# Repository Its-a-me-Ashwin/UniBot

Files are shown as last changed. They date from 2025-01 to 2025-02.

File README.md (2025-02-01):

# UniBot: A Cost-Effective Universal Wheeled Robot Platform

**UniBot** is a versatile, cost-effective robotic platform designed for human-robot interaction (HRI) and navigation-based research projects. With a maximum continuous payload of 45 kg, UniBot can support up to 60 kg when acceleration is reduced, making it ideal for various experimental and research applications.

<!-- ![](https://github.com/Its-a-me-Ashwin/UniBot/blob/main/images/img2.jpeg) | ![]([https://...Ocean.png](https://github.com/Its-a-me-Ashwin/UniBot/blob/main/images/img1.jpeg)) -->

## Features
- **Max Continuous Payload**: 45 kg
- **Max Payload (Reduced Acceleration)**: 60 kg
- **Universal Wheeled Design**: Suitable for indoor navigation and HRI applications
- **Cost-Effective**: Built for under 500 USD
  
## Hardware
All CAD and STL files for the robot platform are available on [Onshape](https://cad.onshape.com/documents/59060569869ff0b1603c8808/w/daa640d62e3ffdb959e3981d/e/3620547f53db6f14c46e0bf9).

### Bill of Materials

# Parts List

| Item | Description | Quantity |
|---|---|---|
| **Motors** | [Scooter Motors](https://www.amazon.com/dp/B0BBVVV962?ref=ppx_yo2ov_dt_b_fed_asin_title) | 2 |
| **Motor Driver** | [ODrive 3.6](https://odriverobotics.com/shop/odrive-v36) | 1 |
| **Toroidal Inductors** | - | 2 |
| **Capacitors** | 22nF [Capacitors](https://www.amazon.com/dp/B094HRK8QX?ref=ppx_yo2ov_dt_b_fed_asin_title) | 6 |
| **Prototype Board** | [Adafruit Prototype Board](https://www.adafruit.com/product/1609) | 1 |
| **M3 Bolts, Nuts, and Spacers** | - | As needed |
| **M8x20 Bolts and Nuts** | - | 24 |
| **M10x10 Bolts and Nuts** | - | 4 |
| **M12x10 Bolts** | - | 4 |
| **Caster Wheels (4cm diameter)** | - | 2 |
| **DC-DC Converter with USB-C PD Output** | eBay | 1 |
| **Battery (36V or 24V, min 2.5Ah)** | eBay | 1 |

## Total Estimated Cost: ~$500 USD

## Software
### Ongoing Development (For Experimental Use)
The initial Python code to configure both scooter motors is available, including a command-line interface (CLI) for controlling both motors. As the software is still in progress, it may be subject to changes. Use with caution in experimental setups.

---

For questions, contributions, or further information, please feel free to reach out or please checkout [this](https://github.com/Its-a-me-Ashwin/SpeedyNav) repo for a n indepth look at its appliacation (in progress).

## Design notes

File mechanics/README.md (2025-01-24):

# Fabrication Instructions

This folder contains all the parts required to build the robot. You will need to **3D-print** several components and **laser-cut** others, based on the details below.

---

## 3D-Printed Parts

- **Material**: Use a tough plastic such as **ABS**.  
- **Infill**: Print with **80% infill** for optimal strength.  
- **Alternative Filaments**: Stronger filaments (e.g., PETG, Nylon, or Carbon Fiber-reinforced) are optional. ABS is sufficient if cost is a concern or you already have it on hand.

---

## Laser-Cut Parts

- **Material Thickness**: All laser-cut parts should be **5 mm** thick.  
- **Material Options**: Acrylic, plywood, MDF, or aluminum.  
- **Recommendations**:  
  - **MDF** and **acrylic** often provide a good balance of cost, availability, and performance.  
  - If weight or rigidity is critical, consider aluminum.  
  - Plywood can also be used for a more natural aesthetic.

---

## Additional Notes

1. **Check CAD Files**: Ensure you have the correct dimensions and tolerances from the design files before fabrication.  
2. **Assembly**: After printing and cutting, verify all parts fit correctly before final assembly.  
3. **Safety**: Follow best practices when using 3D printers, laser cutters, and other fabrication tools.

---

_You can refer back to the main documentation or CAD designs for further details on part orientation, supports, or finishing steps._

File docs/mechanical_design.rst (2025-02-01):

Mechanical Design
=================

CAD Files
---------

Link to the step files. 
**Example**:
`Download CAD Files <../_assets/assembly.zip>`_
It is available at ../_assets/assembly.zip

Exploded Views
--------------

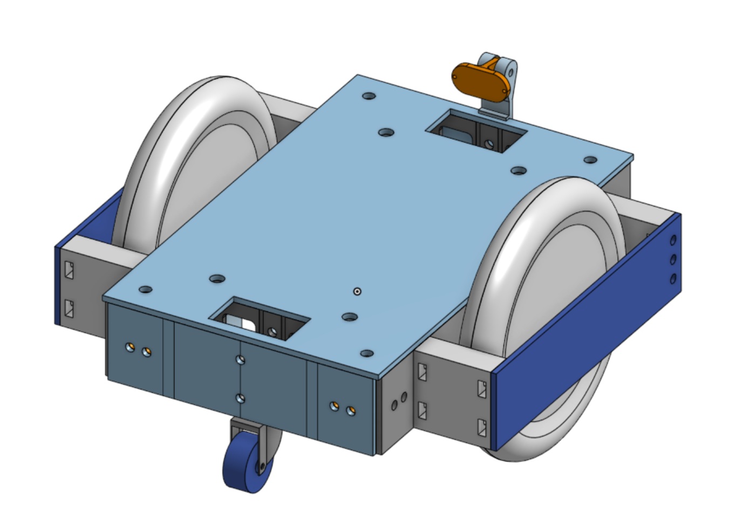
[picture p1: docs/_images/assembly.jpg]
Exploded View


Discuss any important design features or constraints.

Materials & Dimensions
----------------------

.. list-table::
   :widths: 30 50 20
   :header-rows: 1

   * - **Item**
     - **Description**
     - **Quantity**
   * - **Motors**
     - `Scooter Motors <https://www.amazon.com/dp/B0BBVVV962?ref=ppx_yo2ov_dt_b_fed_asin_title>`_
     - 2
   * - **Motor Driver**
     - `ODrive 3.6 <https://odriverobotics.com/shop/odrive-v36>`_
     - 1
   * - **Toroidal Inductors**
     - -
     - 2
   * - **Capacitors**
     - 22nF `Capacitors <https://www.amazon.com/dp/B094HRK8QX?ref=ppx_yo2ov_dt_b_fed_asin_title>`_
     - 6
   * - **Prototype Board**
     - `Adafruit Prototype Board <https://www.adafruit.com/product/1609>`_
     - 1
   * - **M3 Bolts, Nuts, and Spacers**
     - -
     - As needed
   * - **M8x20 Bolts and Nuts**
     - -
     - 24
   * - **M10x10 Bolts and Nuts**
     - -
     - 4
   * - **M12x10 Bolts**
     - -
     - 4
   * - **Caster Wheels (4cm diameter)**
     - -
     - 2
   * - **DC-DC Converter with USB-C PD Output**
     - eBay
     - 1
   * - **Battery (36V or 24V, min 2.5Ah)**
     - eBay
     - 1
   * - **ABS Filament**
     - 500g spool for 3D printing
     - 1
   * - **Material Sheet (Acrylic, Aluminum, or MDF)**
     - 800x600mm piece for structural components
     - 1

**Total Estimated Cost**: ~500 USD

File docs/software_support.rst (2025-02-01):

Software Support
================

Getting Started
---------------

#. **Set up a Raspberry Pi**:
   - If you use a Raspberry Pi or a similar single-board computer, please set it up with an OS.

   - It is recommended to update to the latest version of the OS, set up a WiFi connection, and enable SSH.
   
   - Also, set up Bluetooth and connect a controller to the Raspberry Pi for debugging later. Refer to :doc:`bluetooth_setup` for instructions.

#. **Install Dependencies**:
   - Install Python and the required packages.

   .. code-block:: bash

      sudo apt update
      sudo apt-get install python3 python3-pip

      pip3 install odrive

      cd ~
      git clone https://github.com/<removed-for-anonymity>/Unibot.git
      cd Unibot/code
      pip install -e .

Initial Calibration
-------------------

Run the following command while the robot is on a stand with its wheels free to move. Ensure that the ODrive has power before proceeding.

#. **Configure the ODrive**:

   .. code-block:: bash

      sudo ./Unibot/code/src/config.sh

   This command takes about one minute to run, and the robot's wheels will move during the process. Once it completes, **do not** change the orientation of the wires.

   At this point, your robot is ready to use.

Example Usage of the Repository
-------------------------------

Run the folloing to set up a simple waypoint mission to make the robot move around.

.. code-block:: bash

   #!/usr/bin/env python3
   import time
   from unibot import Unibot
   from unibot import Waypoints, Waypoint  # Or "from unibot.waypoints import Waypoints, Waypoint" if you prefer

   def main():
      # 1. Create your Unibot instance
      unibot = Unibot(max_speed=50, max_acceleration=10)

      # 2. Set the motors to closed-loop control
      unibot.motor_controller.setClosedLoopControl(0)
      unibot.motor_controller.setClosedLoopControl(1)
      print("Motors set to CLOSED-LOOP control.")

      # 3. Define some waypoints
      #    Each Waypoint has a direction (x, y), a speed, a duration, and an optional delay after the move
      waypoints = Waypoints()
      waypoints.add_waypoint(Waypoint(direction=(0, 1), speed=0.5, duration=3.0, delay=1.0))  # Move forward
      waypoints.add_waypoint(Waypoint(direction=(1, 0), speed=0.3, duration=2.0, delay=1.0))  # Turn right
      waypoints.add_waypoint(Waypoint(direction=(0, -1), speed=0.5, duration=3.0, delay=0.5)) # Move backward
      waypoints.add_waypoint(Waypoint(direction=(-1, 0), speed=0.3, duration=2.0, delay=0.0)) # Turn left

      # 4. Execute the waypoints asynchronously
      print("Executing waypoints...")
      waypoints.execute_async(unibot)

      # (Optional) Let the robot do its moves for 10 seconds
      time.sleep(10)

      # 5. Stop execution (if you want to halt prematurely or after finishing)
      print("Stopping waypoints execution...")
      waypoints.stop_execution(unibot)

      # Deactivate the motors or keep them in closed-loop as you see fit
      unibot.motor_controller.setIdle(0)
      unibot.motor_controller.setIdle(1)
      print("Motors set to IDLE. Done.")

   if __name__ == "__main__":
      main()

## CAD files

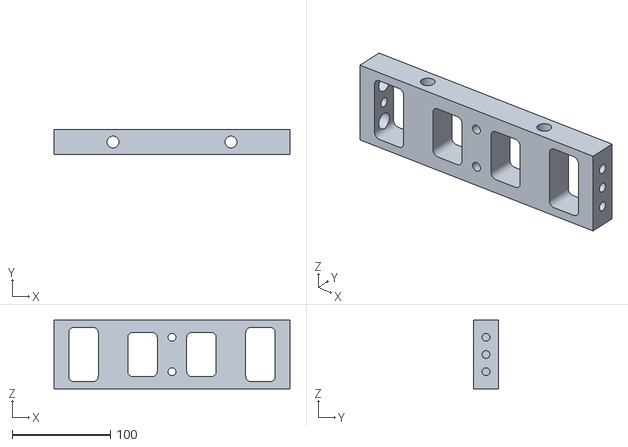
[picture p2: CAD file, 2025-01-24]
mechanics/3d-prints/MainBracket x 2.stl
240.0 x 25.0 x 70.0

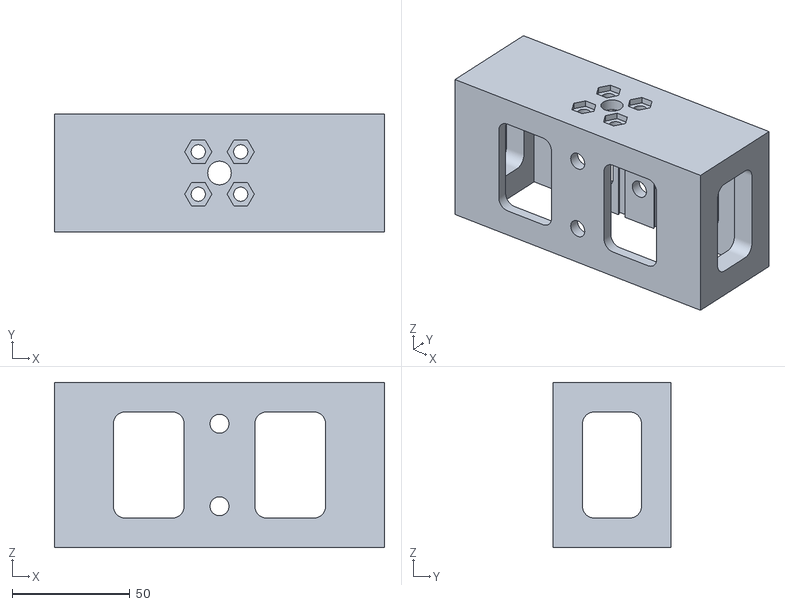
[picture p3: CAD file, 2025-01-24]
mechanics/3d-prints/ChasterWheelHolder x 2.stl
140.0 x 50.0 x 70.0

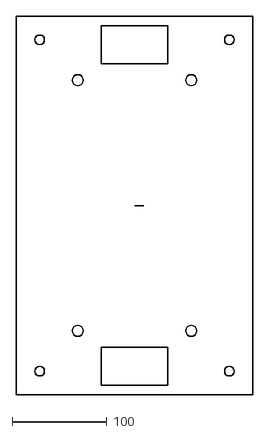
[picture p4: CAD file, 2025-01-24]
mechanics/laser-cuts/TopPlate x 2.dxf
250.0 x 400.0

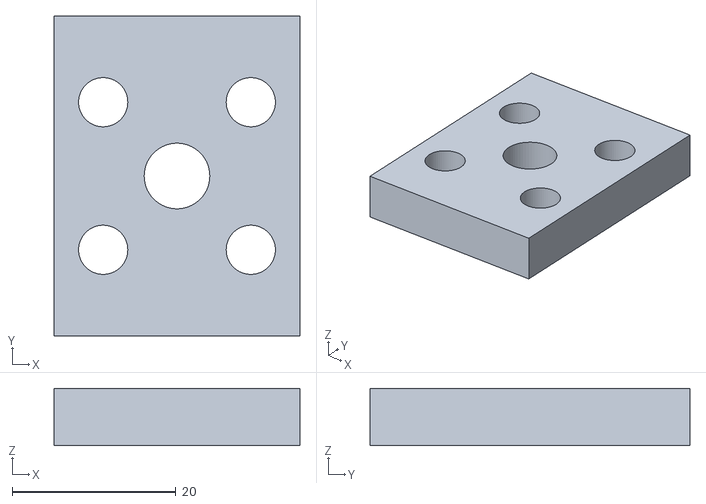
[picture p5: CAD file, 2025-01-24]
mechanics/3d-prints/ChassisWheelAttachment x 2.stl
30.0 x 39.0 x 7.00

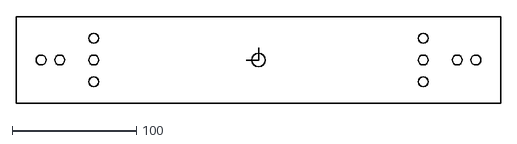
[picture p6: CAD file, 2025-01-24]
mechanics/laser-cuts/SidePlate x 2.dxf
390.0 x 70.0

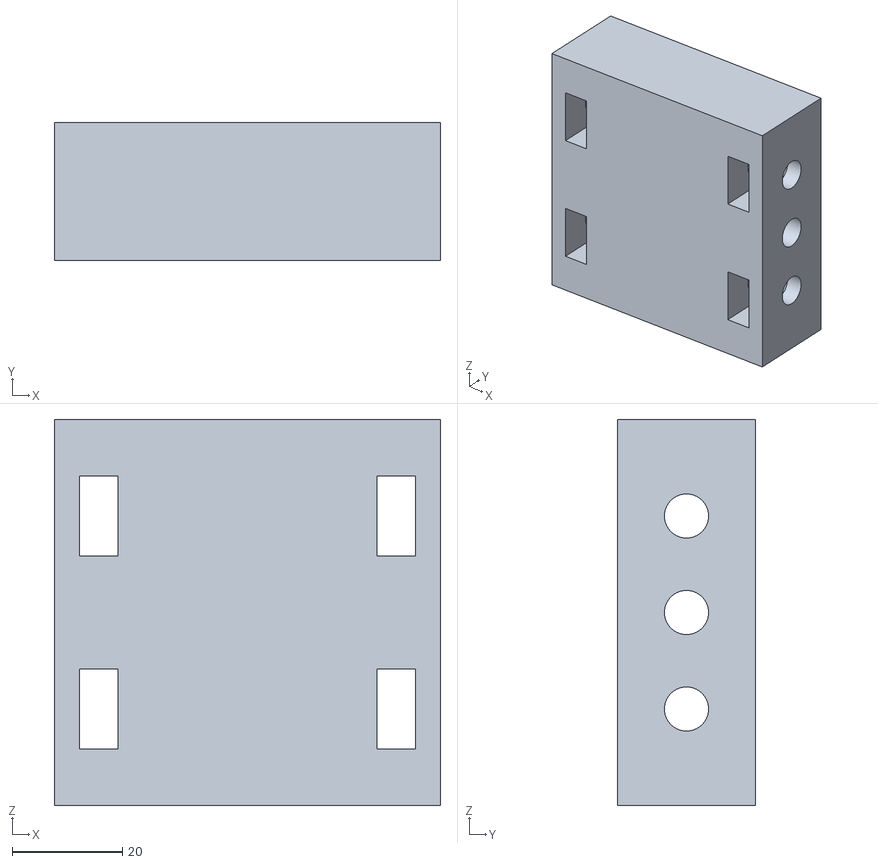
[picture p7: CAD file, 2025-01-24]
mechanics/3d-prints/WheelSpacer x 4.stl
70.0 x 25.0 x 70.0

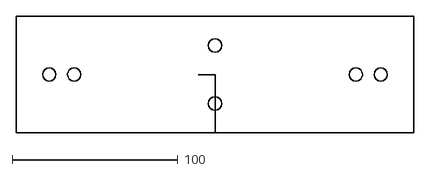
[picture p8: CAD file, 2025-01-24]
mechanics/laser-cuts/FrontPlate x 2.dxf
240.0 x 70.0

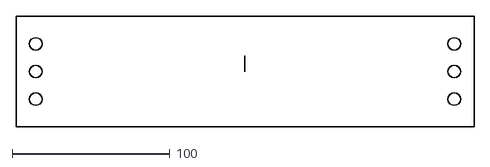
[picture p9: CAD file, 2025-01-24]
mechanics/laser-cuts/WheelHolder x 2.dxf
290.0 x 70.0

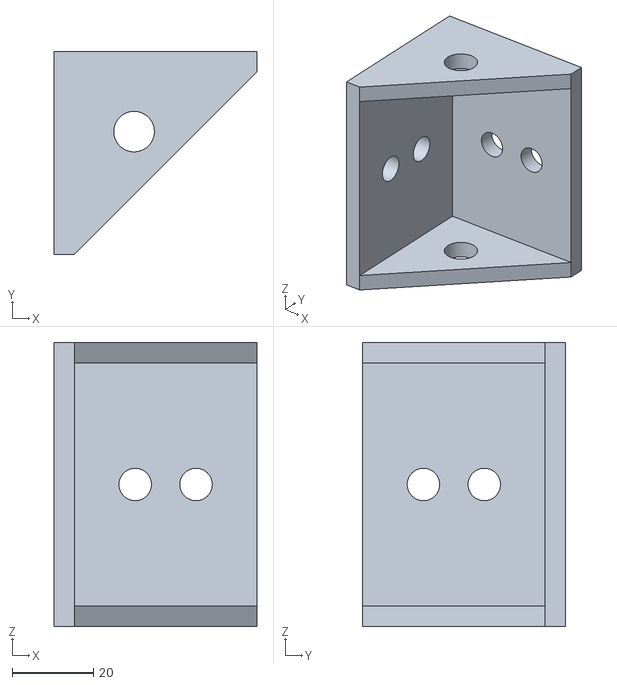
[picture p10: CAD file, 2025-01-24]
mechanics/3d-prints/LBracket x 4.stl
50.0 x 50.0 x 70.0

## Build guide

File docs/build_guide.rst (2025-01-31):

Build Guide
===========

Introduction
------------

This page walks you through assembling the robot step by step. It also provides an overview of the necessary tools, materials, and prerequisites.

Mechanical Assembly
-------------------

#. **Print or Laser-Cut Parts**: Instructions on how to obtain the mechanical parts.
#. **Gather Fasteners**: List of required screws, nuts, washers, etc.

#. **Parts List**:
   - 3D print all the necessary parts. It is recommended to use ASA or ABS with 80% infill and at least 8 walls to increase strength.
   - Laser-cut all the provided DXF files using either acrylic or MDF. Non-structural plates, such as the bottom plate, can be cut from plywood.

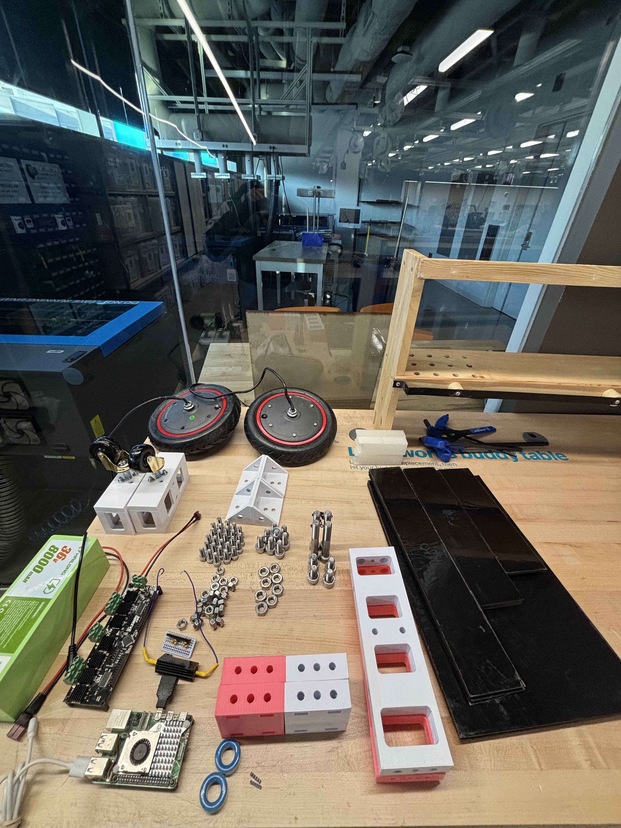
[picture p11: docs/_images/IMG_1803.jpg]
Assembly Step 1


#. **Building Steps**:

   #. **Step 1**:
      Gather the main brackets and bolts.

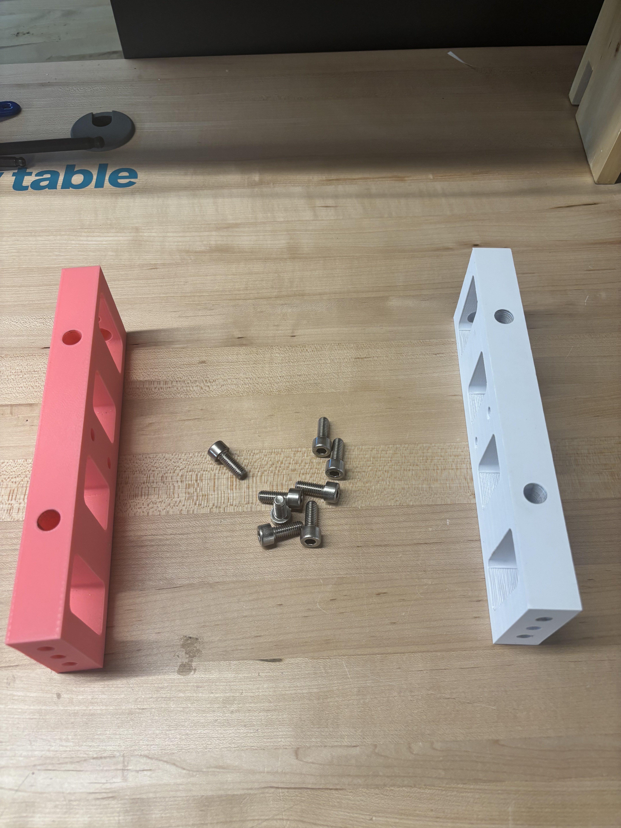
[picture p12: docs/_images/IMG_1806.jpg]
   

   #. **Step 2**:
      Assemble the main brackets and bolts.

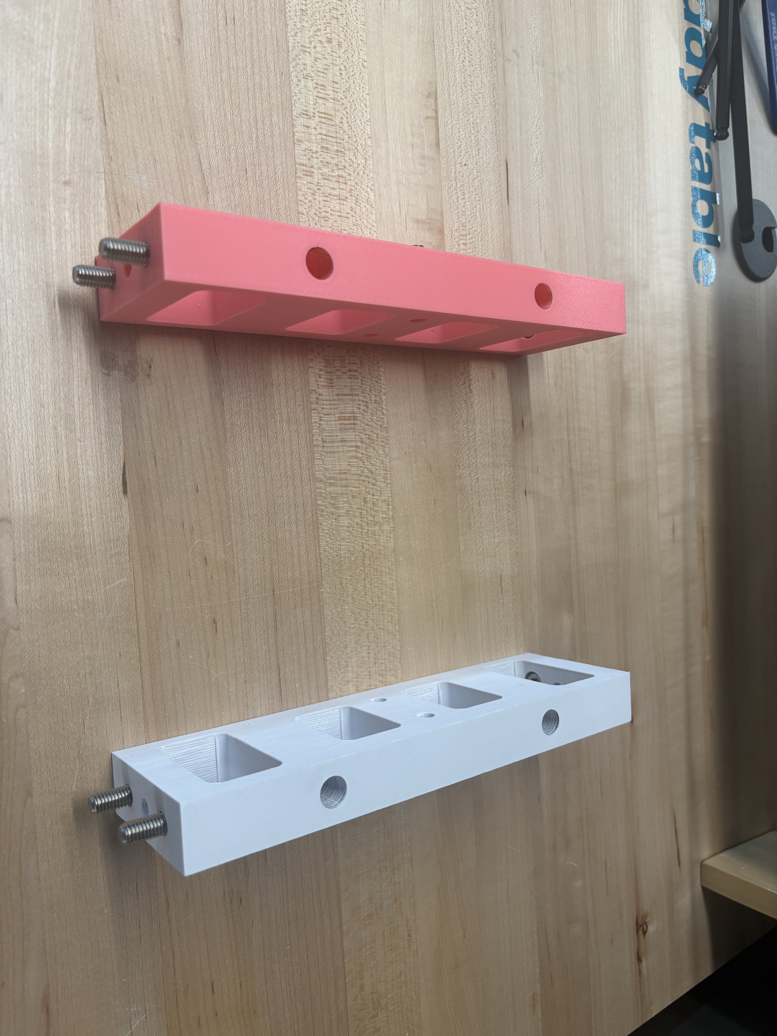
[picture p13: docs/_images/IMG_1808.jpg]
   

   #. **Step 3**:
      Attach the two longer boards to the main brackets using eight M8x20 bolts. The bolts will be loose for now, which is fine.

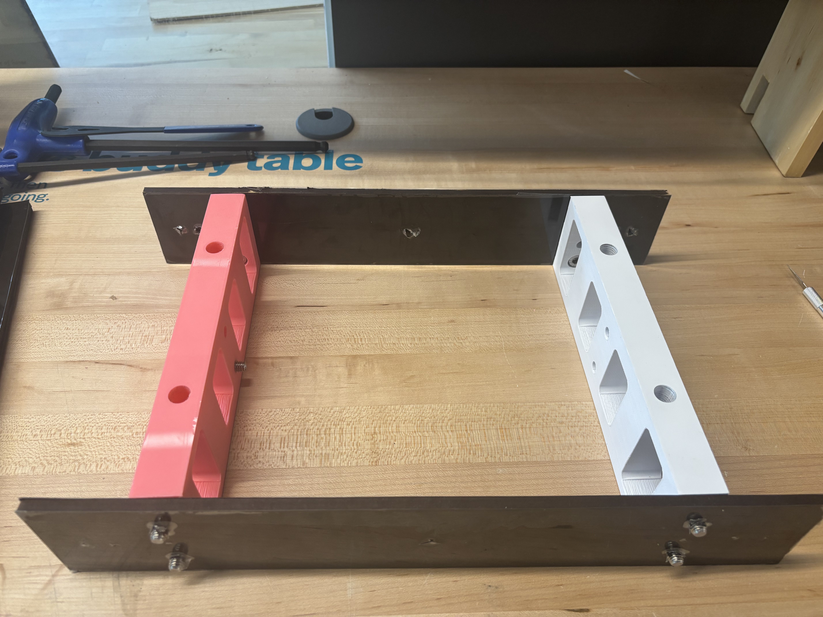
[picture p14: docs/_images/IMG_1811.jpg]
   

   #. **Step 4**:
      Insert the M8 nuts into the holes in the spacers. Tighten all eight M8x20 bolts using an Allen key with a rounded head.

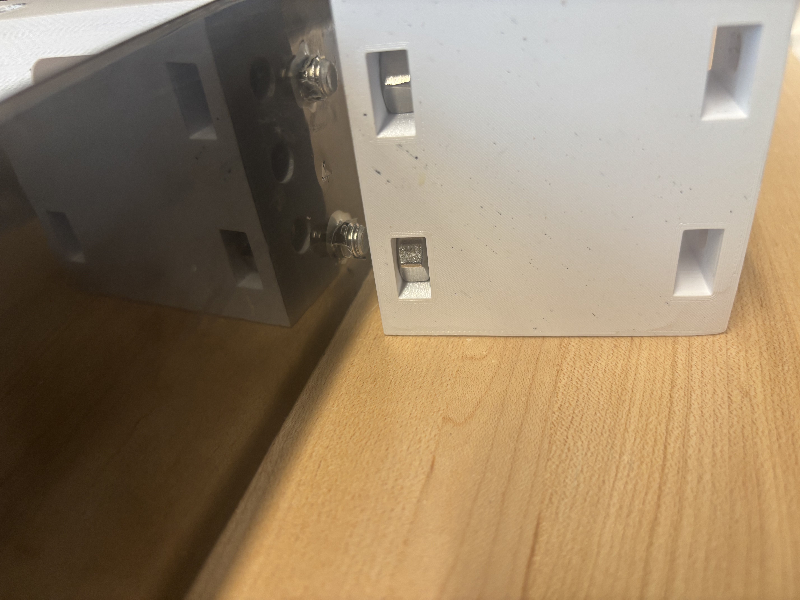
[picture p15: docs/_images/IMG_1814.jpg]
   

   #. **Step 5**:
      Get the angled brackets and attach them to the main frame using M8x20 bolts.

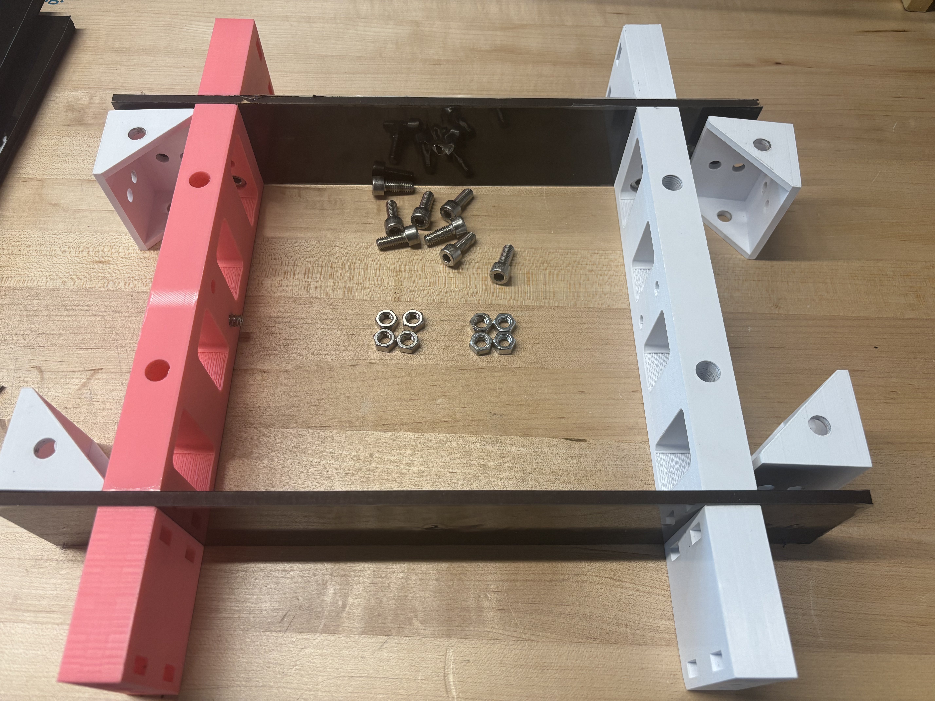
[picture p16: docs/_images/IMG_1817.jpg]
   

   #. **Step 6**:
      Get the two front panels and four M8x20 bolts and nuts. Attach the front and back panels as shown.

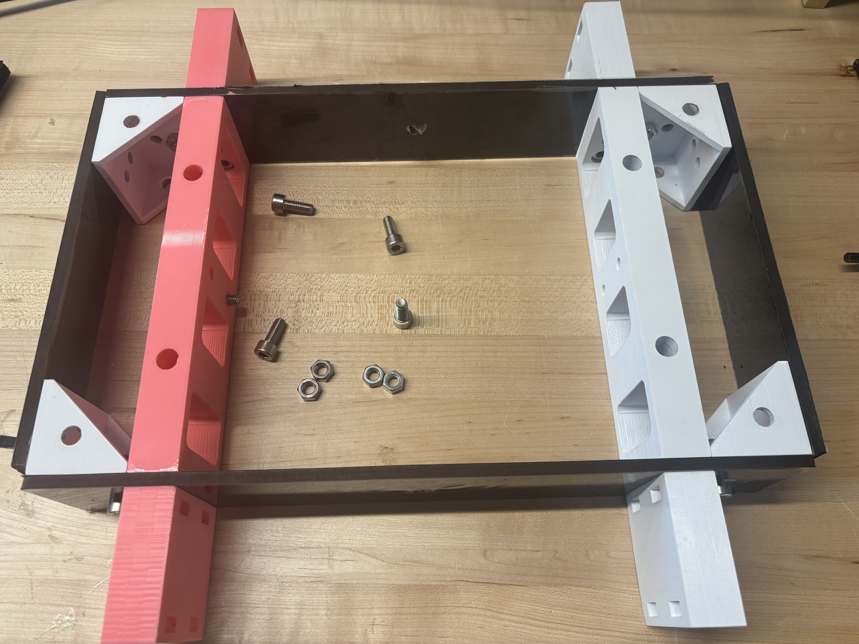
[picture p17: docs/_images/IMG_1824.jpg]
   

   #. **Step 7**:
      Get the M10x20 bolts and attach them through the bottom holes on the angled brackets. Refer to the pictures for details. Use a long Allen key to tighten the bolts.

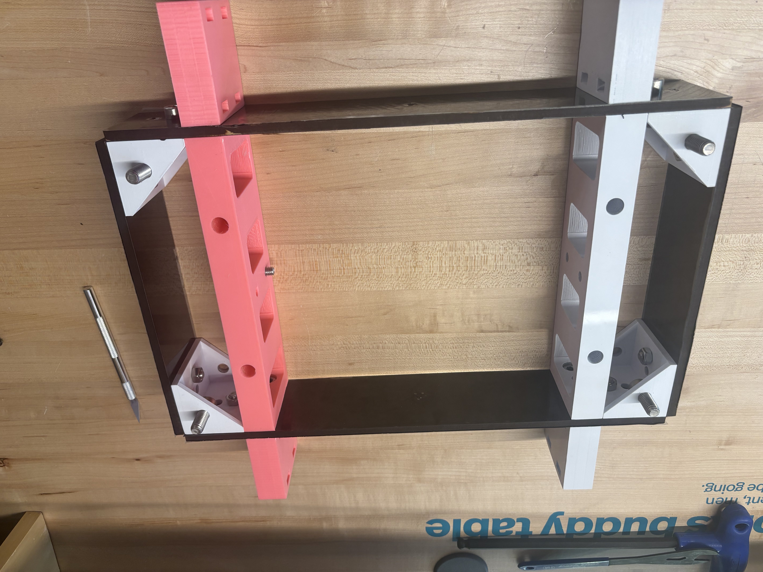
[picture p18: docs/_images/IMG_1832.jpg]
   

   #. **Step 8**:
      Attach the bottom plate (the one with holes for the electronics) to the angled brackets using M10 bolts and nuts. Use M12x10 bolts to reinforce the attachment to the main bracket.

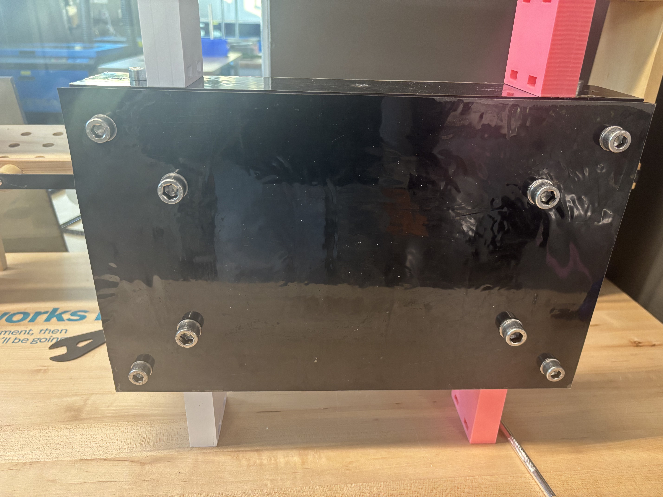
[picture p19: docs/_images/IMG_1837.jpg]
   

   #. **Step 9**:
      Place the robot on its side as shown in the picture. This is how it should look.

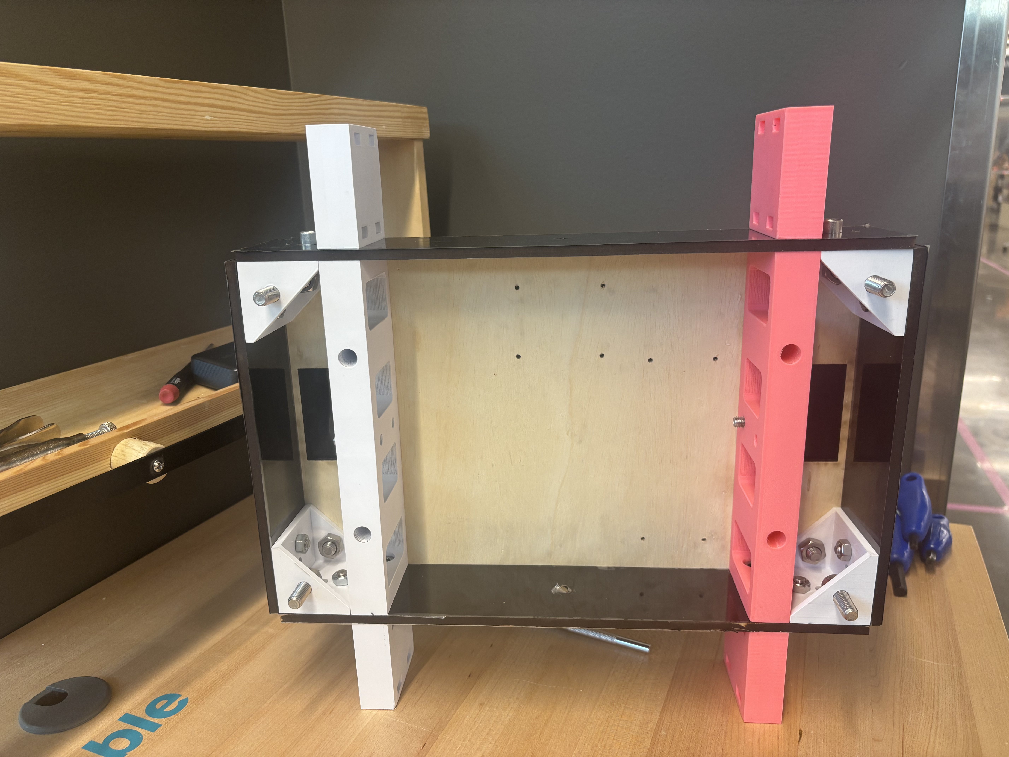
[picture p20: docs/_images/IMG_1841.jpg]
   

   #. **Step 10**:
      Attach the main board (Raspberry Pi 5) using M3 standoffs, nuts, and nylon bolts.

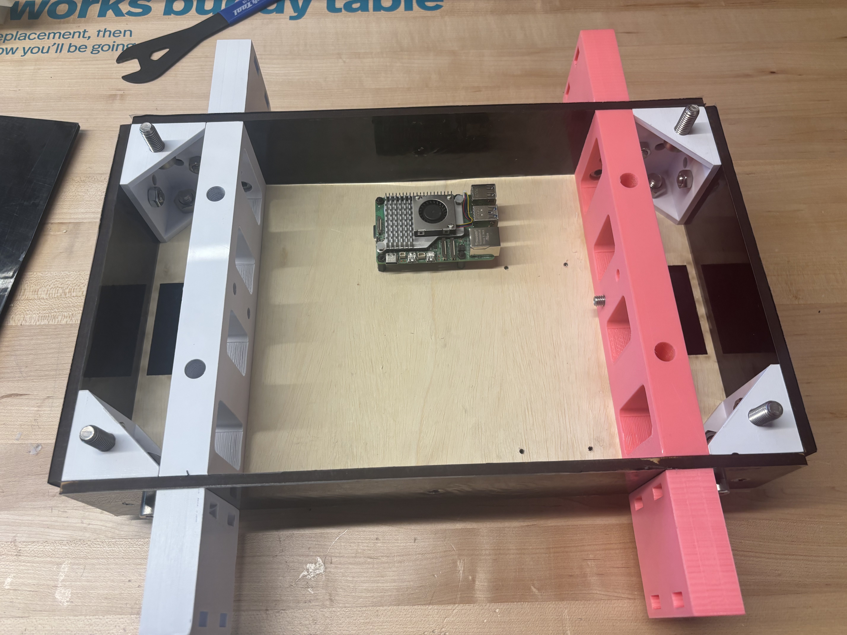
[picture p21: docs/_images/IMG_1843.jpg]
   

   #. **Step 11**:
      Install the scooter motor. Carefully insert the wires into the hole on the side bracket and tighten the main bolt into the panel.
      Ensure that no orthogonal force is applied to the axis, as this may stress the panels. Instead, rotate the bolt while keeping the motor upright to tighten it.

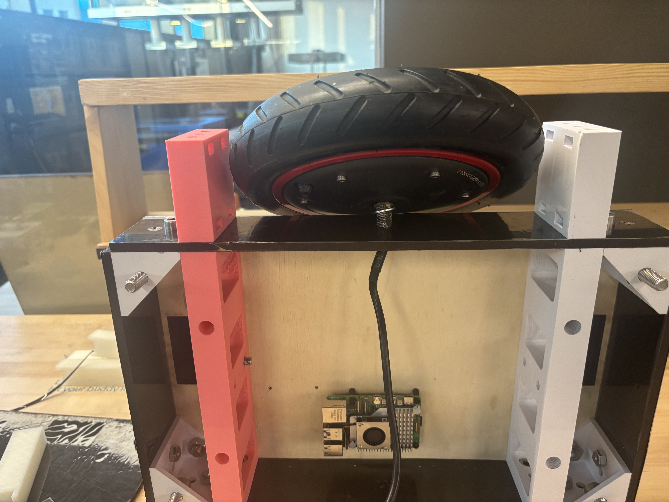
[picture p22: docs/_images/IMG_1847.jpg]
   

   #. **Step 12**:
      Use a nut to secure the motor bolt. Apply a small amount of Loctite to prevent it from loosening due to vibrations.

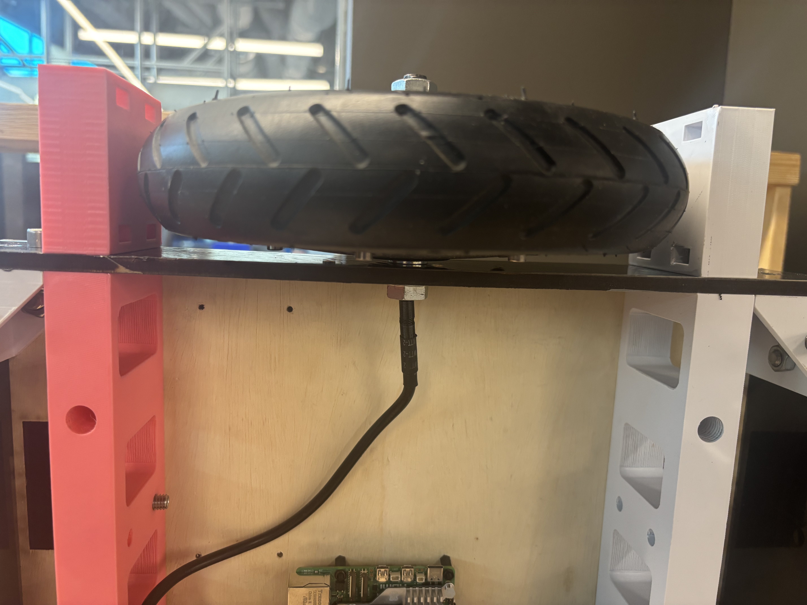
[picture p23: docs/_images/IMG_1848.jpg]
   

   #. **Step 13**:
      Get the outer panel and tighten the motor’s nut and bolt. Also, secure it to the spacers using four M8x20 bolts and nuts.

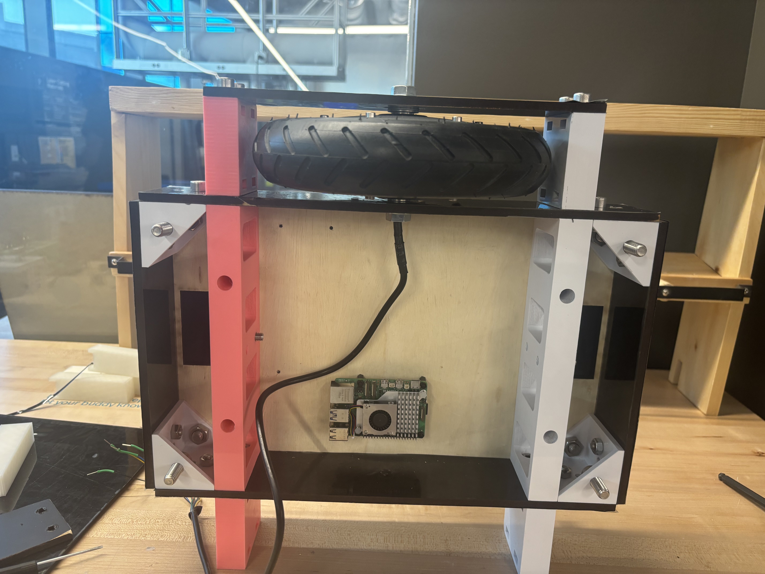
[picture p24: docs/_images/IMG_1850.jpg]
   

   #. **Step 14**:
      Repeat the previous steps to attach the second motor to the other side. Manage the wiring accordingly. You can trim the wires if this is the final setup for the motors.

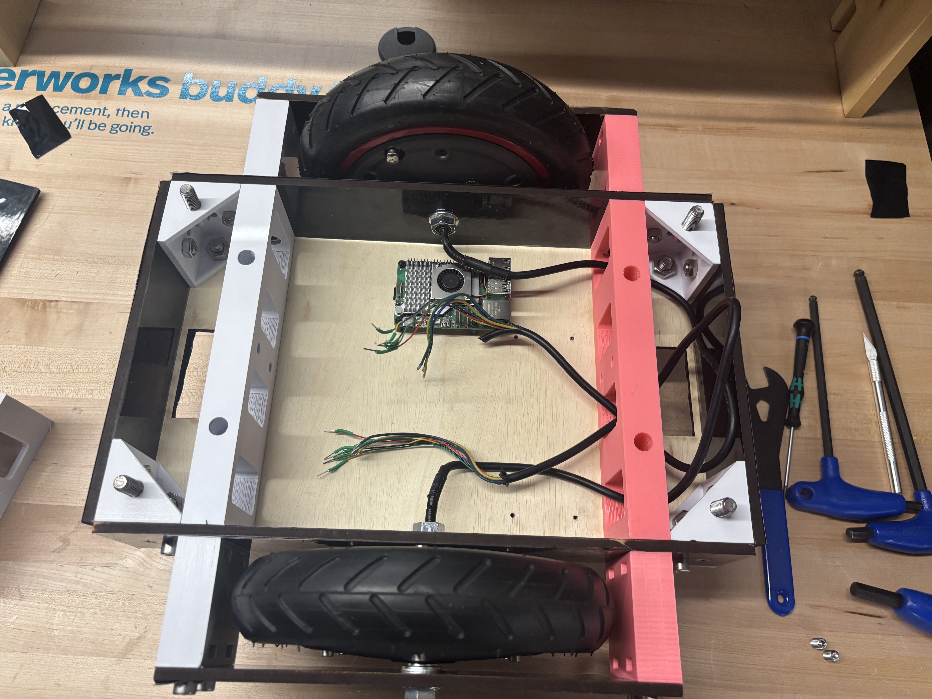
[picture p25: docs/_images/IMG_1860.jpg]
   

   #. **Step 15**:
      Insert the caster wheel holders. Ensure that the springs are installed and that the suspension system functions correctly before final assembly.

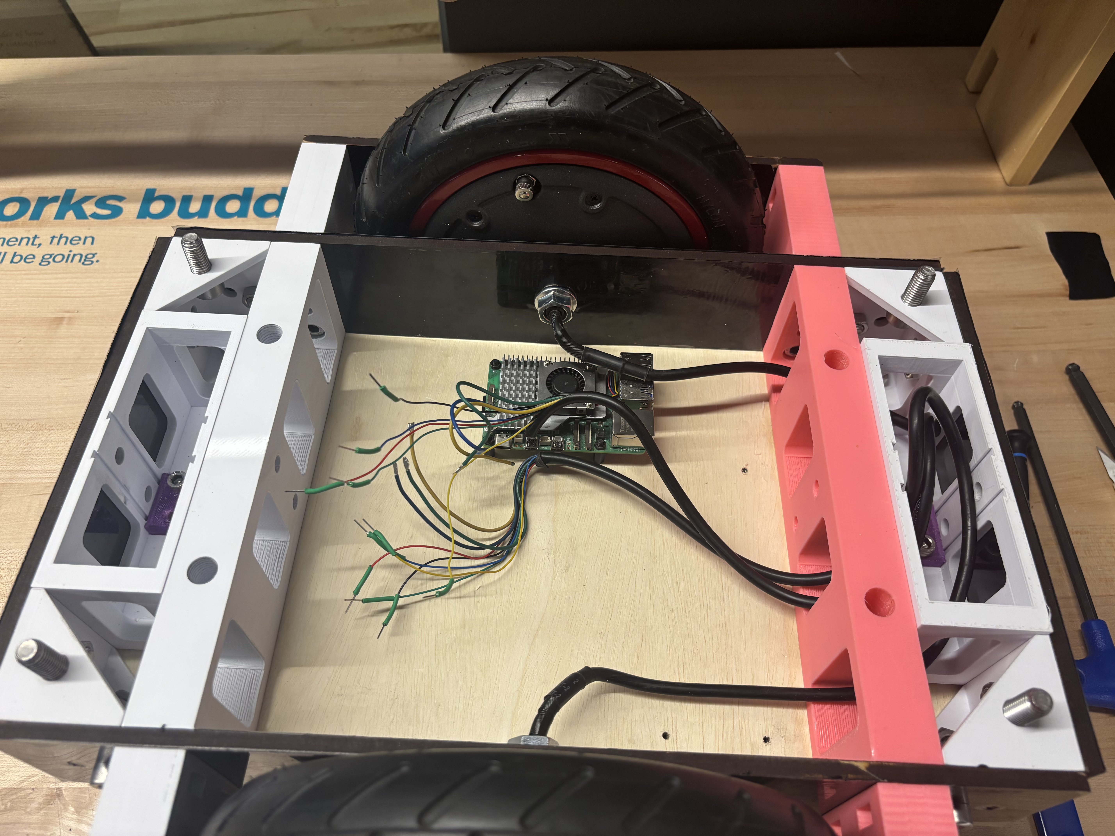
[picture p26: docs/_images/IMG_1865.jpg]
   

   #. **Step 16**:
      Secure the caster wheel holders using an M8 bolt and M8 grub nut. These bolts will later be used to attach the depth camera.

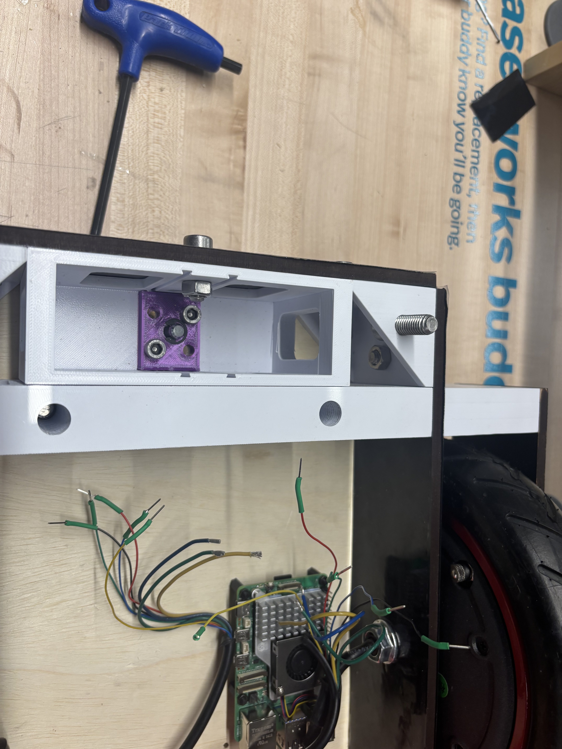
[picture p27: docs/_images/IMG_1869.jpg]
   

   #. **Step 17**:
      Install the ODrive controller using M3 standoffs and nuts.

      - Prepare the wires by adding toroid cores at the end of the power wires for the motor.
      - Add male pin connectors to the signal wires.
      - The format should be: **+ A B C -**, where:
        - Red = Positive
        - Black = Negative
        - Green, Blue, Yellow = Motor phase wires (order may vary).

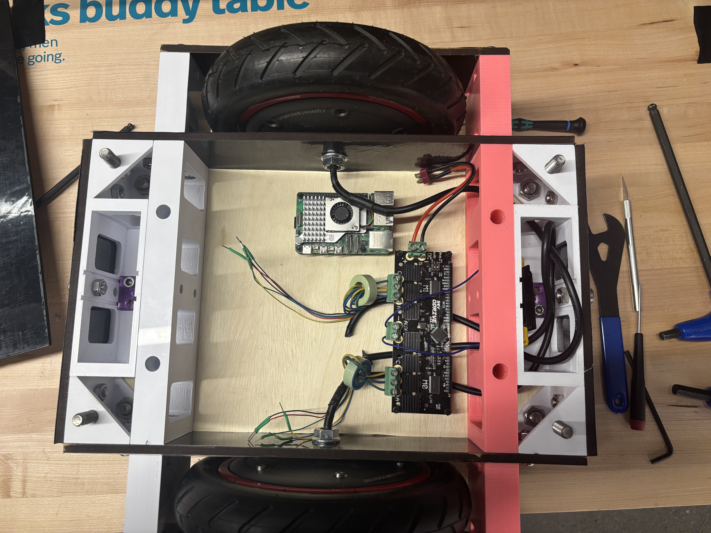
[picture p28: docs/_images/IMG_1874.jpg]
   

   #. **Step 18** (Optional):
      Add 44nF capacitors between ground and all control signals on the ODrive.
      Connect the encoder wires to the ODrive and add a power resistor (2Ω, 50W) between the power input and ground.

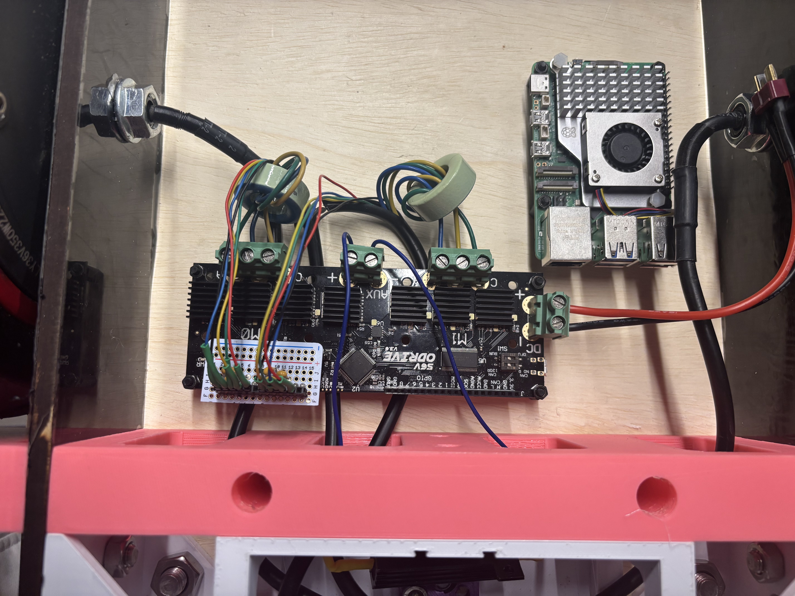
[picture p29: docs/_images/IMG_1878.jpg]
   

   #. **Step 19**:
      Place the main battery in the remaining space. 

      - For the demonstration, the largest battery that fits is used.
      - Any battery above **24V and 3Ah** should be sufficient.
      - Use a **DC-DC converter** with a USB-C output to power the Raspberry Pi.
      - Connect the ODrive to the Raspberry Pi via USB.
      - Add a power switch between the battery, ODrive, and DC-DC regulator.
      - Route the battery’s charging cable to the top plate for easy access.

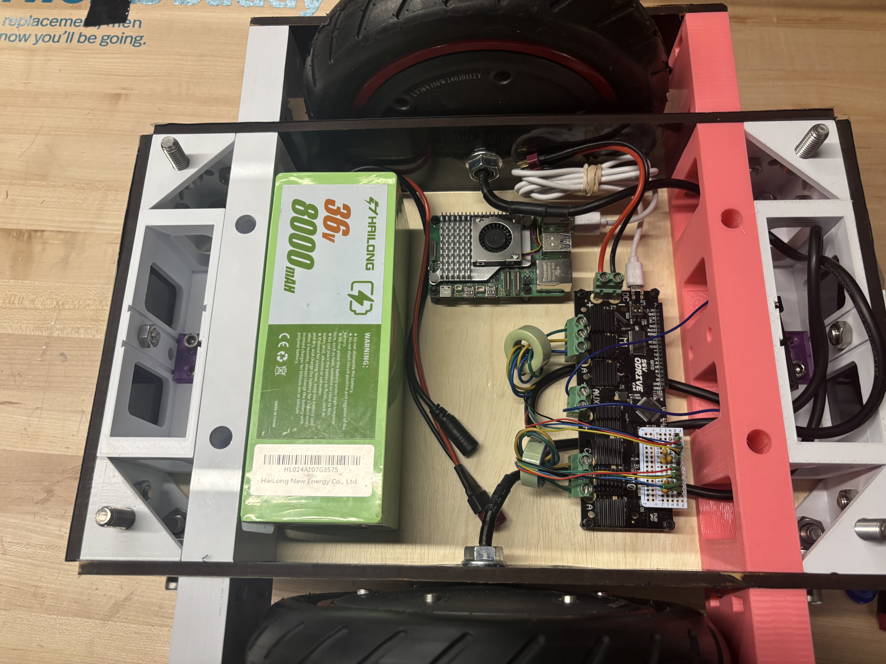
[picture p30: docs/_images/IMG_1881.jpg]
   

   #. **Step 20**:
      Secure the top plate using M10 nuts. If carrying a payload, use M12 bolts of any length (M12x70 bolts are used in the demo).

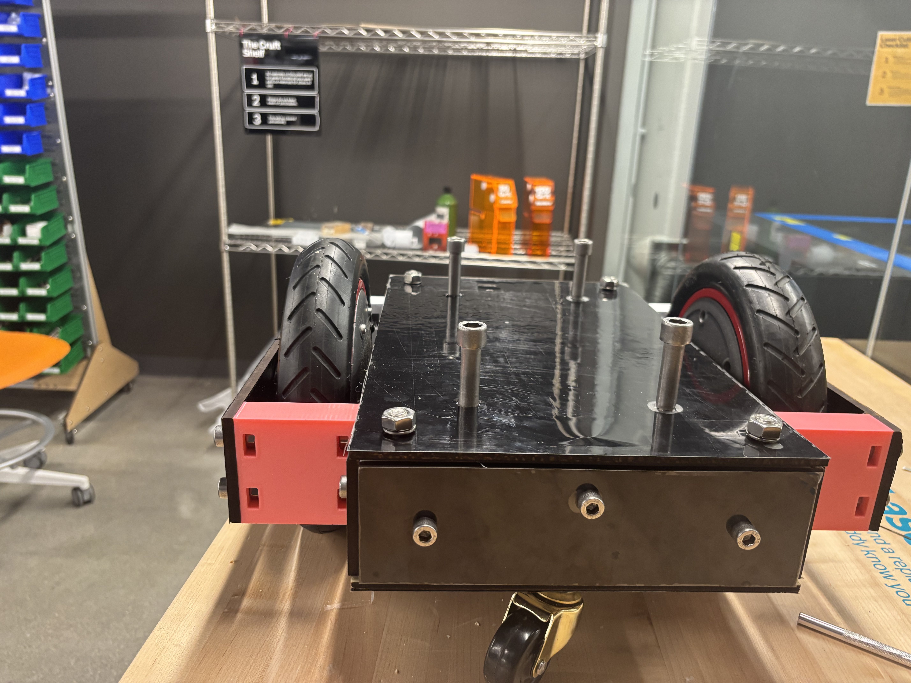
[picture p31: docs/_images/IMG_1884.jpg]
   

   #. **Step 21**:
      Place the robot on a stand for initial testing and calibration.

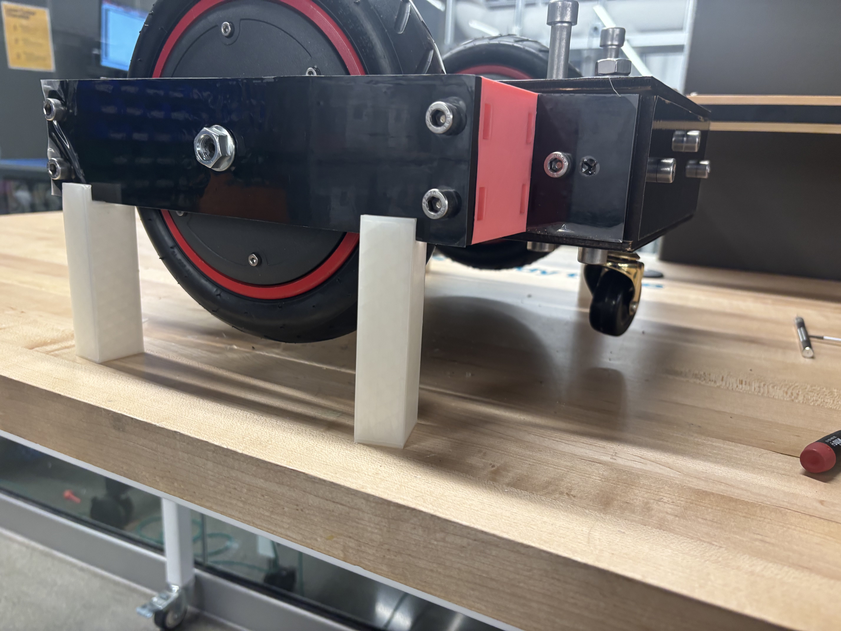
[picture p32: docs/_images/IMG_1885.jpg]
   

Testing
-------

Once assembled, perform a quick check to ensure that all components move freely. Refer to the software setup guide to fully test the robot. Mechanical assembly is now complete.

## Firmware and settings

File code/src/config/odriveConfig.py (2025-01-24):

#!/usr/bin/env python3
import argparse
import sys
import time

import odrive
from odrive.enums import (AXIS_STATE_CLOSED_LOOP_CONTROL,
                          AXIS_STATE_ENCODER_HALL_POLARITY_CALIBRATION,
                          AXIS_STATE_ENCODER_OFFSET_CALIBRATION,
                          AXIS_STATE_IDLE, AXIS_STATE_MOTOR_CALIBRATION,
                          CONTROL_MODE_POSITION_CONTROL, ENCODER_MODE_HALL)


class HBMotorConfig:
    HOVERBOARD_KV = 16.0
    MIN_PHASE_INDUCTANCE = 0
    MAX_PHASE_INDUCTANCE = 0.001
    MIN_PHASE_RESISTANCE = 0
    MAX_PHASE_RESISTANCE = 0.5
    ENCODER_OFFSET_FLOAT_TOLERANCE = 0.05

    def __init__(self, axis_num: int, anticogging_cal: bool, erase_config: bool) -> None:
        self.axis_num = axis_num
        self.anticogging_cal = anticogging_cal
        self.erase_config = erase_config

        print("Looking for ODrive...")
        self._find_odrive()
        print("Found ODrive.")

    def _find_odrive(self) -> None:
        self.odrv = odrive.find_any()
        self.odrv_axis = getattr(self.odrv, f"axis{self.axis_num}")

    def configure(self) -> None:
        if self.erase_config:
            print("Erasing pre-existing configuration...")
            try:
                self.odrv.erase_configuration()
            except Exception as e:
                print(f"Error erasing configuration: {e}")

        self._find_odrive()

        self.odrv.config.enable_brake_resistor = True
        self.odrv_axis.motor.config.pole_pairs = 15
        self.odrv_axis.motor.config.resistance_calib_max_voltage = 4
        self.odrv_axis.motor.config.requested_current_range = 25
        self.odrv_axis.motor.config.current_control_bandwidth = 100
        self.odrv_axis.motor.config.torque_constant = 8.27 / self.HOVERBOARD_KV
        self.odrv_axis.encoder.config.mode = ENCODER_MODE_HALL
        self.odrv_axis.encoder.config.cpr = 90
        self.odrv_axis.encoder.config.calib_scan_distance = 150
        self.odrv_axis.encoder.config.bandwidth = 100
        self.odrv_axis.controller.config.pos_gain = 6
        self.odrv_axis.controller.config.vel_gain = (
            0.02
            * self.odrv_axis.motor.config.torque_constant
            * self.odrv_axis.encoder.config.cpr
        )
        self.odrv_axis.controller.config.vel_integrator_gain = (
            0.1
            * self.odrv_axis.motor.config.torque_constant
            * self.odrv_axis.encoder.config.cpr
        )
        self.odrv_axis.controller.config.vel_limit = 10
        self.odrv_axis.controller.config.control_mode = CONTROL_MODE_POSITION_CONTROL

        self.odrv_axis.requested_state = AXIS_STATE_IDLE
        try:
            print("Saving manual configuration and rebooting...")
            is_saved = self.odrv.save_configuration()
            if not is_saved:
                print("Error: Configuration not saved. Are all motors in IDLE state?")
            else:
                print("Configuration saved.")
        except Exception as e:
            print(f"Error saving configuration: {e}")

        self._find_odrive()

        print("Calibrating motor...")
        self.odrv_axis.requested_state = AXIS_STATE_MOTOR_CALIBRATION
        time.sleep(10)

        if self.odrv_axis.motor.error != 0:
            print(f"Motor calibration error: {self.odrv_axis.motor.error}")
            sys.exit(1)

        if not (self.MIN_PHASE_INDUCTANCE <= self.odrv_axis.motor.config.phase_inductance <= self.MAX_PHASE_INDUCTANCE):
            print(f"Phase inductance error: {self.odrv_axis.motor.config.phase_inductance}")
            sys.exit(1)

        if not (self.MIN_PHASE_RESISTANCE <= self.odrv_axis.motor.config.phase_resistance <= self.MAX_PHASE_RESISTANCE):
            print(f"Phase resistance error: {self.odrv_axis.motor.config.phase_resistance}")
            sys.exit(1)

        self.odrv_axis.motor.config.pre_calibrated = True

        print("Calibrating hall encoder polarity...")
        self.odrv_axis.requested_state = AXIS_STATE_ENCODER_HALL_POLARITY_CALIBRATION
        time.sleep(15)

        if self.odrv_axis.encoder.error != 0:
            print(f"Encoder polarity calibration error: {self.odrv_axis.encoder.error}")
            sys.exit(1)

        print("Calibrating encoder offset...")
        self.odrv_axis.requested_state = AXIS_STATE_ENCODER_OFFSET_CALIBRATION
        time.sleep(30)

        if self.odrv_axis.encoder.error != 0:
            print(f"Encoder offset calibration error: {self.odrv_axis.encoder.error}")
            sys.exit(1)

        self.odrv_axis.encoder.config.pre_calibrated = True

        if self.anticogging_cal:
            print("Calibrating anticogging...")
            self.odrv_axis.requested_state = AXIS_STATE_CLOSED_LOOP_CONTROL
            self.odrv_axis.controller.start_anticogging_calibration()

            while self.odrv_axis.controller.config.anticogging.calib_anticogging:
                time.sleep(15)
                print("Still calibrating anticogging...")

            if self.odrv_axis.controller.error != 0:
                print(f"Anticogging calibration error: {self.odrv_axis.controller.error}")
                sys.exit(1)

            self.odrv_axis.controller.config.anticogging.pre_calibrated = True

        self.odrv_axis.requested_state = AXIS_STATE_IDLE
        try:
            print("Saving final configuration and rebooting...")
            self.odrv.save_configuration()
            print("Final configuration saved.")
        except Exception as e:
            print(f"Error saving final configuration: {e}")

        self._find_odrive()
        print("Configuration complete.")

    def mode_idle(self) -> None:
        self.odrv_axis.requested_state = AXIS_STATE_IDLE

    def mode_close_loop_control(self) -> None:
        self.odrv_axis.requested_state = AXIS_STATE_CLOSED_LOOP_CONTROL

    def move_input_pos(self, angle: float) -> None:
        self.odrv_axis.controller.input_pos = angle / 360.0


if __name__ == "__main__":
    parser = argparse.ArgumentParser(description="Hoverboard Motor Calibration")
    parser.add_argument("--axis_num", type=int, choices=[0, 1], required=True, help="Motor axis number to perform calibration on (0 or 1).")
    parser.add_argument("--erase_config", action="store_true", help="Erase ODrive board's current configuration.")
    parser.add_argument("--anticogging_cal", action="store_true", help="Calibrate for anti-cogging.")
    parser.add_argument("--motor_test", action="store_true", help="Test motor movement post calibration.")

    args = parser.parse_args()

    hb_motor_config = HBMotorConfig(
        axis_num=args.axis_num,
        anticogging_cal=args.anticogging_cal,
        erase_config=args.erase_config,
    )
    hb_motor_config.configure()

    if args.motor_test:
        print("Testing motor movement in closed-loop control...")
        hb_motor_config.mode_close_loop_control()

        ## Make a 180 turn on the motor
        for angle in range(0, 210, 30):
            print(f"Moving motor to {angle} degrees.")
            hb_motor_config.move_input_pos(angle)
            time.sleep(5)

        print("Setting motor to idle mode.")
        hb_motor_config.mode_idle()

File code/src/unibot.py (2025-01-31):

import odrive
import math
import threading
import time
from odrive.enums import (
    AXIS_STATE_IDLE,
    AXIS_STATE_CLOSED_LOOP_CONTROL,
    CONTROL_MODE_POSITION_CONTROL,
    CONTROL_MODE_VELOCITY_CONTROL
)
import argparse
import json

from waypoints import Waypoint, Waypoints
from recording import Recording
from exceptions import ODriveError
class ODriveMotorControl:
    def __init__(self, max_velocity, max_acceleration, verbose=False):
        """Initialize ODriveMotorControl class."""
        self.odrv = None
        self.odrvAxis0 = None
        self.odrvAxis1 = None
        self.verbose = verbose

        self.max_velocity = max_velocity
        self.max_acceleration = max_acceleration

        self._initialize_odrive()

    def _initialize_odrive(self):
        """Initialize and configure ODrive."""
        try:
            self.odrv = self._findOdrive()
            self.odrvAxis0 = self.odrv.axis0
            self.odrvAxis1 = self.odrv.axis1

            # Set the max velocity and ramp rate for both axes
            self._setMaxLimits(self.odrvAxis0)
            self._setMaxLimits(self.odrvAxis1)
        except Exception as e:
            print(f"Error initializing ODrive: {e}")
            self._handle_error(str(e))

    def _findOdrive(self):
        """Connect to ODrive."""
        print("Looking for ODrive...")
        return odrive.find_any()

    def _setMaxLimits(self, axis):
        """Set maximum velocity and ramp rate for an axis."""
        try:
            axis.controller.config.vel_limit = self.max_velocity
            axis.controller.config.vel_ramp_rate = self.max_acceleration
        except Exception as e:
            print(f"Error setting max limits: {e}")
            self._handle_error(str(e))

    def setAcceleration(self, acceleration):
        """Set the velocity ramp rate for both motors."""
        self.max_acceleration = acceleration
        try:
            self.odrvAxis0.controller.config.vel_ramp_rate = acceleration
            self.odrvAxis1.controller.config.vel_ramp_rate = acceleration
        except Exception as e:
            print(f"Error setting acceleration: {e}")
            self._handle_error(str(e))

    def setVelocity(self, axis_num, velocity):
        """Set the motor to move with a specified velocity."""
        if abs(velocity) > self.max_velocity:
            raise ValueError(f"Velocity cannot exceed {self.max_velocity} RPM.")

        try:
            axis = self._getAxis(axis_num)
            axis.controller.config.control_mode = CONTROL_MODE_VELOCITY_CONTROL
            axis.controller.input_vel = velocity
        except Exception as e:
            print(f"Error setting velocity: {e}")
            self._handle_error(str(e))

    def moveRelativePosition(self, axis_num, degrees):
        """
        Move motor by specified degrees relative to its current position.
        """
        try:
            axis = self._getAxis(axis_num)
            current_position = axis.encoder.pos_estimate
            target_position = current_position + (degrees / 360.0)
            axis.controller.config.control_mode = CONTROL_MODE_POSITION_CONTROL
            axis.controller.input_pos = target_position
        except Exception as e:
            print(f"Error moving relative position: {e}")
            self._handle_error(str(e))

    def setClosedLoopControl(self, axis_num):
        """Set the motor to closed-loop control mode."""
        try:
            axis = self._getAxis(axis_num)
            axis.requested_state = AXIS_STATE_CLOSED_LOOP_CONTROL
        except Exception as e:
            print(f"Error setting closed-loop control: {e}")
            self._handle_error(str(e))

    def setIdle(self, axis_num):
        """Set the motor to idle mode."""
        try:
            axis = self._getAxis(axis_num)
            axis.requested_state = AXIS_STATE_IDLE
        except Exception as e:
            print(f"Error setting idle mode: {e}")
            self._handle_error(str(e))

    def _getAxis(self, axis_num):
        """Retrieve the axis object based on axis number."""
        try:
            if axis_num == 0:
                return self.odrvAxis0
            elif axis_num == 1:
                return self.odrvAxis1
            else:
                raise ValueError("Invalid axis number. Must be 0 or 1.")
        except Exception as e:
            print(f"Error retrieving axis: {e}")
            self._handle_error(str(e))

    def _handle_error(self, message):
        """
        Handle errors by spawning a thread to reinitialize ODrive in the background.
        Raises an ODriveError to provide an error struct back to the caller.
        """
        error_struct = {
            "message": f"ODrive error occurred: {message}",
            "time": time.time(),
            "details": "Reinitialization attempt started in background thread."
        }

        def reinit_worker():
            try:
                print("Handling ODrive error in background. Resetting ODrive...")
                self.odrv.reboot()
                time.sleep(10)  # Wait for reboot
                print("Reinitializing ODrive in background thread...")
                self._initialize_odrive()
                print("Reinitialization complete.")
            except Exception as reinit_e:
                print(f"Failed to recover from error in background: {reinit_e}")

        reinit_thread = threading.Thread(target=reinit_worker, daemon=True)
        reinit_thread.start()

        # Raise an exception so caller can handle the error immediately
        raise ODriveError(error_struct)
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
